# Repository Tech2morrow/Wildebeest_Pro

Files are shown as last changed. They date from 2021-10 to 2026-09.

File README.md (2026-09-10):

<p align="center">
  Wildebeest Pro — open autonomous robotics platform
</p>

<p align="center">
  
  
  
  
  
  
</p>

Wildebeest Pro is a complete reference implementation for a compact, four-wheel skid-steer autonomous robot. It combines an NVIDIA Jetson-class autonomy computer, an Arduino Uno safety-oriented base controller, LiDAR, camera, IMU, GNSS, ultrasonic ranging, reproducible simulation, and equivalent ROS 2 and ROS 1 interfaces.

> **Commissioning status:** the software, firmware, documentation, mock transports, and simulation models are implemented and host-tested. The physical robot has **not** been electrically or mechanically validated by this repository. Keep motor power disconnected until the BOM blockers, wiring checks, calibration, and staged acceptance tests are complete. This is not a safety-rated machine.

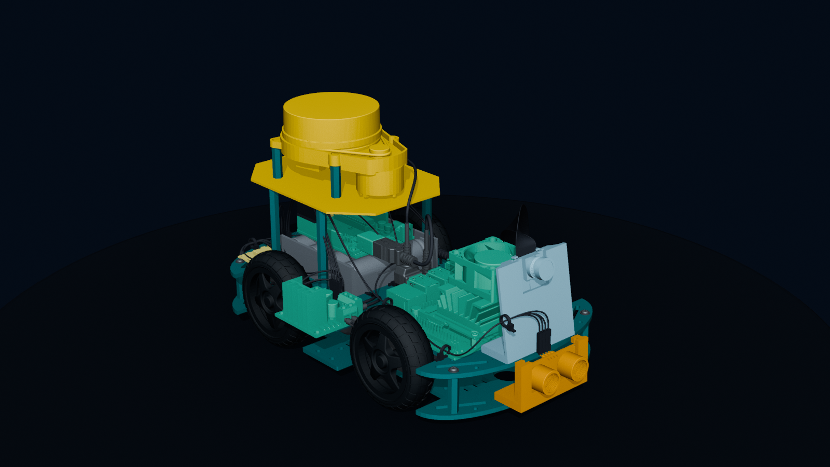
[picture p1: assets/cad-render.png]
Actual Wildebeest Pro CAD assembly rendered from the 595 placed STL components


## What is included

| Area | ROS 2 Jazzy | ROS 1 Noetic | Shared contract |
|---|---:|---:|---|
| Four-wheel description, TF, RViz | Yes | Yes | CAD-derived `33.622 mm` wheel radius, `121.843 mm` track, `117.150 mm` wheelbase |
| Serial base bridge and deterministic mock | Yes | Yes | CRC-16 frames, exact firmware identity gate, 300 ms MCU watchdog |
| Velocity arbitration and E-stop latch | Yes | Yes | navigation, teleop, joystick, and dashboard inputs require fresh commands |
| Encoder/IMU fusion and GNSS option | Yes | Yes | `/wheel/odometry`, `/odometry/filtered`, REP-103/105 frames |
| Navigation and mapping | Nav2 / SLAM Toolbox | move_base / gmapping | common sensor and frame semantics |
| Physics simulation | Gazebo Harmonic | Gazebo Classic legacy | four driven wheels and timeout-protected commands |
| Operator dashboard | Browser | Browser | rosbridge UI with offline-safe controls and responsive layout |

The ROS 2 path is recommended for new work. ROS 1 Noetic is maintained here as a migration and legacy profile; upstream Noetic is end-of-life.

## Run the software-only robot on any development PC

The most reproducible path is Docker Desktop (Windows/macOS) or Docker Engine with Compose (Linux). Git LFS is only needed when you want the full mechanical corpus.

```bash
git clone https://github.com/Tech2morrow/Wildebeest_Pro.git
cd Wildebeest_Pro
git lfs install
git lfs pull
```

Start the recommended ROS 2 mock robot:

```bash
docker compose --profile ros2 up --build ros2-mock
```

Or start the ROS 1 compatibility profile:

```bash
docker compose --profile ros1 up --build ros1-mock
```

These commands run the complete graph with a deterministic software base, so no serial device or motor hardware is required. Stop with `Ctrl+C`.

### Native ROS 2 on Ubuntu 24.04

```bash
./scripts/bootstrap.sh ros2
./scripts/build.sh ros2
source ros2_ws/install/setup.bash
ros2 launch wildebeest_bringup robot.launch.py use_sim:=true
```

For Gazebo physics:

```bash
ros2 launch wildebeest_gz simulation.launch.py use_rviz:=true
```

### Native ROS 1 on Ubuntu 20.04

```bash
./scripts/bootstrap.sh ros1
./scripts/build.sh ros1
source ros1_ws/devel/setup.bash
roslaunch wildebeest_bringup robot.launch use_sim:=true
```

For the legacy Gazebo demo:

```bash
roslaunch wildebeest_simulation demo.launch
```

The original Jetson Nano software image is not a native ROS 2 Jazzy target. The handbook explains supported split-compute, container, replacement-SBC, and ROS 1 legacy options before you choose an image.

## Architecture

```mermaid
flowchart LR
    L[2D LiDAR] --> J[Jetson autonomy]
    C[IMX219 camera] --> J
    G[GNSS] --> J
    J --> N[Localization, mapping, navigation]
    D[Dashboard / joystick] --> M[Velocity mux + E-stop gate]
    N --> M
    M --> B[ROS base bridge]
    B <-->|CRC-checked serial| A[Arduino Uno controller]
    A --> W[Four motors / wheels]
    E[Side encoders] --> A
    I[MPU6050 + ultrasonic] --> A
    A --> B
```

All command sources pass through arbitration. The base bridge will not move until it receives the exact firmware boot identity, an E-stop release cannot replay an old command, and both hardware and simulation paths stop on stale velocity input. See the [interface contract](docs/software/interfaces.md) and [serial protocol](docs/reference/serial-protocol.md).

### Sensor identification palette

The same high-contrast palette is applied to sensor visuals in ROS 1, ROS 2, RViz, Gazebo, and the CAD showcase. Colors identify hardware only; they never indicate live health or status.

| Sensor | Visual color | Hex |
|---|---|---|
| 2D LiDAR | Orange | `#E69F00` |
| MPU6050 IMU | Rose | `#CC79A7` |
| GNSS receiver | Yellow | `#F0E442` |
| IMX219 camera | Sky blue | `#56B4E9` |
| Front ultrasonic | Vermillion | `#D55E00` |

## Firmware, dashboard, and documentation

Build the Arduino Uno firmware with PlatformIO:

```bash
python -m pip install platformio
platformio run -d firmware/wildebeest_base
```

Run the local operator dashboard (Node.js 20+):

```bash
node dashboard/dev-server.mjs
```

Then open `http://127.0.0.1:8088/`. Live operation additionally requires a trusted rosbridge endpoint; the UI never bypasses the velocity multiplexer.

Build the handbook locally:

```bash
python -m pip install mkdocs-material
mkdocs serve -f docs/mkdocs.yml
```

Start with the [readiness guide](docs/getting-started.md), then follow [wiring](docs/hardware/wiring.md), [assembly](docs/hardware/assembly.md), [calibration](docs/calibration.md), and the [acceptance plan](docs/testing.md) in order. The spreadsheet [commissioning BOM](BOM/Wildebeest_Pro_BOM.xlsx) opens with a deliberate **BLOCKED** gate until safety-critical selections are verified.

## Mechanical design

The authoritative native model is [`Wildebeest_Pro_P&G.SLDASM`](<3D_Mechanical_Design/P&G Wildebeest_Pro/Wildebeest_Pro_P&G.SLDASM>). A matching `177 MB` AP203 [`Wildebeest_Pro_P&G.STEP`](<3D_Mechanical_Design/P&G Wildebeest_Pro/Wildebeest_Pro_P&G.STEP>) is available for CAD tools without SolidWorks. The requested `.asm` file does not exist; `.SLDASM` is the actual SolidWorks assembly.

The corpus also contains 595 placed component STL files. Read the [CAD guide](3D_Mechanical_Design/README.md) and [audited manifest](3D_Mechanical_Design/MANIFEST.md) before exporting ROS meshes: the raw files use millimetres, assembly coordinates, and more than 2.8 million triangles. The repository uses lightweight link-local primitives for portable runtime simulation and preserves the detailed sources through Git LFS.

Recreate the showcase image from the checked-in CAD exports with Blender 5.2+:

```bash
blender --background --python tools/render_cad.py -- --output assets/cad-render.png
```

## Repository map

| Path | Purpose |
|---|---|
| `ros2_ws/` | Primary Jazzy packages: base, bringup, description, Nav2, Gazebo |
| `ros1_ws/` | Noetic-compatible base, bringup, description, navigation, simulation |
| `firmware/wildebeest_base/` | Uno motor/encoder controller and fail-safe serial protocol |
| `config/robot.toml` | Version-neutral geometry, limits, serial, power, and topic defaults |
| `dashboard/` | Dependency-free mission-control web interface |
| `docs/` | MkDocs handbook, safety case, tests, operations, and troubleshooting |
| `BOM/` | Filterable commissioning workbook with cost formulas and release gate |
| `3D_Mechanical_Design/` | SolidWorks, STEP, STL, appearance, and CAD audit files |
| `tools/` | Protocol codec, mock MCU, preflight doctor, tests, and CAD renderer |

## Verify a checkout

On Windows:

```powershell
python -m pip install -r requirements-ci.txt
.\scripts\test.ps1
```

On Linux:

```bash
python3 -m pip install -r requirements-ci.txt
./scripts/test.sh
```

CI repeats protocol, dashboard, manifest, documentation, firmware, and container-build gates without downloading the 500+ MiB CAD corpus. Physical commissioning results must be recorded separately; a green software build is not evidence that an energized robot is safe.

## Contributing, credits, and licensing

Contributions are welcome through [the contributor guide](CONTRIBUTING.md). Security-sensitive reports follow [SECURITY.md](SECURITY.md).

Wildebeest Pro was created by Muhammed Nabeel. Thanks to Mr. Anouar Dhouibi for assistance with the original joystick teleoperation GUI concept, and to every open-source project on which this implementation builds.

Original project software and documentation are provided under the [MIT License](LICENSE). CAD and embedded vendor/reference assets may have separate or unconfirmed rights; inclusion does not relicense them. Review [THIRD_PARTY_NOTICES.md](THIRD_PARTY_NOTICES.md) before redistribution or commercial use.

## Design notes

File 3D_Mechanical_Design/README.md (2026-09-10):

# Wildebeest Pro mechanical design

This directory preserves the native SolidWorks design, a neutral STEP export,
and the component-level STL export set for the complete robot assembly.

Some component models, textures, and appearances have unconfirmed third-party
provenance. Read the repository [third-party notice](../THIRD_PARTY_NOTICES.md)
before redistributing or using the CAD corpus commercially.

## Start here

The authoritative top-level assembly is
[`Wildebeest_Pro_P&G.SLDASM`](<P&G Wildebeest_Pro/Wildebeest_Pro_P&G.SLDASM>).
The `.asm` filename mentioned in early project notes does not exist; `.SLDASM`
is the native SolidWorks assembly extension.

Users without SolidWorks can open the matching AP203 exchange model,
[`Wildebeest_Pro_P&G.STEP`](<P&G Wildebeest_Pro/Wildebeest_Pro_P&G.STEP>),
in a STEP-capable CAD program. There is **no single master assembly STL** in
this revision. The 595 `.STL` files are per-component exports whose filenames
begin with `Wildebeest_Pro_P&G -`.

Large CAD and mesh files are stored with Git LFS. After cloning, retrieve them
before opening the model:

```bash
git lfs install
git lfs pull
```

See [MANIFEST.md](MANIFEST.md) for checksums, measured mesh bounds, the sensor
evidence in the assembly, and the ROS export policy.

## Units and coordinate handling

The STEP file explicitly declares millimetres. STL does not carry unit
metadata, but the component coordinates match the millimetre-scale STEP model.
Unmodified STL files therefore require a `0.001` scale in URDF/Xacro.

Do not treat the current CAD origin or axes as a ROS frame. Before publishing a
production mesh:

1. Reorient it to REP-103 (`x` forward, `y` left, `z` up).
2. Put the base origin on the ground-plane projection of the chassis centre.
3. Export in metres, or explicitly apply `scale="0.001 0.001 0.001"`.
4. Use a decimated mesh for visuals and primitives or convex hulls for
   collision. Never use the 2.8-million-triangle component set as collision
   geometry.
5. Keep one normalized mesh per rigid ROS link. The assembly-exported STLs have
   transforms baked into their vertex coordinates and are not link-local.

The checked-in ROS descriptions intentionally use lightweight primitives until
a normalized, reviewed visual mesh is released. That keeps cloning, simulation,
collision checking, and CI practical.

## LiDAR and ranging-model status

The assembly contains `LiDAR Plate.SLDPRT` and its component STL. It also
contains a sensor model named `Radar_mb_1r2t_v1` in SolidWorks, STEP, and STL
formats. No RPLIDAR, YDLIDAR, LDS, or other explicitly named LiDAR sensor body
was found in the native/exchange corpus. Confirm the physical sensor model and
measure its optical origin before setting `laser_frame` or driver parameters.

## Engineering release checklist

Before manufacturing or hardware commissioning:

1. Resolve suppressed or missing references in the original SolidWorks version.
2. Assign real materials, mass, inertia, and centre-of-mass properties.
3. Check interference, fastener engagement, cable bend radius, ventilation,
   wheel clearance, and service access.
4. Create controlled drawings with tolerances and revision identifiers.
5. Measure the assembled wheel radius, left/right wheel-centre separation, and
   every sensor transform. CAD-derived values in the manifest are useful
   cross-checks, not substitutes for measurement.

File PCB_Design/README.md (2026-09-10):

# Electronics design status

The concept repository did not contain an editable schematic or PCB layout. The
current reference implementation therefore uses a documented, fused wiring
harness and off-the-shelf modules; it does **not** pretend that an unreviewed PCB
exists.

Before creating a carrier PCB, freeze the selected motor driver, regulator,
LiDAR interface, connectors and peak-current budget. A releasable design must
include source schematics, ERC/DRC reports, fabrication outputs, assembly BOM,
pick-and-place data, connector pinout, mounting drawing, revision marking,
power-on test plan and a license. See [`docs/hardware/wiring.md`](../docs/hardware/wiring.md)
for the current interconnect contract.

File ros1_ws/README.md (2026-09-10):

# Wildebeest Pro — ROS 1 Noetic compatibility workspace

This catkin workspace provides a complete ROS 1 path for the Wildebeest Pro four-wheel skid-steer robot: a CRC-protected Arduino bridge, side-encoder odometry, MPU6050 and HC-SR04 topics, NEO-6M/LiDAR/IMX219 launches, robot description, `robot_localization`, `move_base`, joystick/keyboard/remote command arbitration, diagnostics, and a Gazebo Classic autonomous demo.

> **Legacy support:** ROS Noetic reached end of life on 31 May 2025. It targets Ubuntu 20.04; the common Jetson Nano JetPack 4 image is Ubuntu 18.04 and cannot use official Noetic binaries directly. Use a maintained Ubuntu 20.04 environment/container or choose the repository's ROS 2 workspace for new deployments. Camera and GPIO access from containers needs host-specific integration.

The nominal wheel/chassis dimensions are CAD-derived: 0.033622 m radius, 0.025065 m wheel width, 0.121843 m left/right centre track, 0.117150 m axle wheelbase, and a 0.257 x 0.150 x approximately 0.031 m shell. They—and all limits, pin mappings, mass properties, covariance values, controller gains, and voltage thresholds—are **unverified commissioning defaults**. Skid-steer scrub means the effective track used by odometry usually differs from the CAD centre track. The software has mock/static tests but has not been validated on the author's physical hardware.

## Packages

| Package | Role |
| --- | --- |
| `wildebeest_base` | Safe serial transport, protocol validation, odometry, IMU/range/battery/diagnostic publication, software e-stop, and deterministic mock MCU |
| `wildebeest_description` | CAD-proportioned four-wheel URDF/Xacro, all sensor frames, four velocity transmissions, RViz model view, and Gazebo sensor hooks |
| `wildebeest_navigation` | Local encoder/IMU EKF, optional GNSS transform/global EKF, AMCL + `move_base`, GMapping, costmaps, and a smoke-test map |
| `wildebeest_bringup` | Hardware sensors, command mux, joystick, diagnostics, udev rules, and a composable robot launch |
| `wildebeest_simulation` | Gazebo Classic arena, `gazebo_ros_control`, four-wheel skid-steer control, sensors, RViz, and integrated navigation demo |

## Build

On an Ubuntu 20.04 machine with ROS Noetic installed:

```bash
cd ros1_ws
bash tools/install_noetic_dependencies.sh
source /opt/ros/noetic/setup.bash
catkin_make -DCMAKE_BUILD_TYPE=Release
source devel/setup.bash
```

Install the Arduino alias rule only after inspecting its VID/PID and adding a serial number if necessary:

```bash
bash tools/install_udev_rule.sh
```

The single source of truth for Arduino firmware is `../firmware/wildebeest_base`. It starts stopped, rejects malformed/out-of-range commands, reports hard/software stop state, and enforces a 300 ms command watchdog.

## Run without hardware

The fastest integration path uses Gazebo:

```bash
roslaunch wildebeest_simulation demo.launch
```

Send an initial pose if AMCL has not converged, then use RViz's **2D Nav Goal** tool. To smoke-test only the hardware graph and exact serial codec with an in-process MCU:

```bash
roslaunch wildebeest_bringup robot.launch use_sim:=true
```

`use_sim:=true` selects the mock base and disables physical sensor/joystick drivers by default; granular arguments may override those choices. BOOT always leaves the base stopped. Deliberately clear it, then send a fresh velocity command:

```bash
rosservice call /base/set_estop "data: false"
```

The mock follows the same wire protocol, watchdog, side-encoder kinematics, and soft-stop path as the serial transport. It is not a physics, exact sensor-timing, or hardware-safety qualification.

## Run on the robot

After wiring, firmware upload, calibration, and raised-wheel safety checks:

```bash
roslaunch wildebeest_bringup robot.launch
```

Useful profiles:

```bash
# Known indoor map: AMCL owns map -> odom
roslaunch wildebeest_bringup robot.launch navigation:=true map:=/absolute/path/site.yaml

# Create a map: GMapping owns map -> odom
roslaunch wildebeest_bringup robot.launch mapping:=true navigation:=false

# Outdoor GNSS fusion: global EKF owns map -> odom
roslaunch wildebeest_bringup robot.launch use_gps_localization:=true navigation:=false mapping:=false
```

`mapping:=true` takes precedence if both legacy mode booleans are supplied, so
GMapping and AMCL can never publish `map -> odom` together. With
`localization:=true` the local EKF owns `odom -> base_link`; with it disabled,
the base bridge becomes the single transform authority.

Never enable AMCL, GMapping, and the global GPS EKF together. The local EKF owns
`odom -> base_link` whenever localization is enabled; otherwise the base bridge
owns it. The MPU6050 has no absolute heading sensor, so the GNSS profile uses
odometry yaw and requires deliberate field validation.

## Stable interfaces

| Direction | Topic/service | Type / purpose |
| --- | --- | --- |
| Input | `/cmd_vel` | `geometry_msgs/Twist`, consumed only by the base bridge |
| Input | `/cmd_vel/remote` | Dashboard/remote `geometry_msgs/Twist` input to the mux; 0.35 s timeout, below local teleoperation |
| Input | `/wildebeest/estop` | `std_msgs/Bool`; locks the mux and latches/releases the MCU software stop |
| Input | `/base/set_estop` | `std_srvs/SetBool` service alternative |
| Input | `/base/reset_odometry` | `std_srvs/Empty`; reset the host-integrated raw odometry origin |
| Output | `/wheel/odometry` | Raw `nav_msgs/Odometry` from encoders |
| Output | `/odometry/filtered` | Local EKF estimate |
| Output | `/imu/data_raw` | Raw MPU6050 acceleration/rate; orientation is explicitly unavailable |
| Output | `/range/front` | `sensor_msgs/Range` from HC-SR04 |
| Output | `/battery_state` | `sensor_msgs/BatteryState` |
| Sensor | `/scan`, `/gps/fix`, `/camera/image_raw` | LiDAR, GNSS, and camera driver outputs |
| Health | `/diagnostics`, `/diagnostics_agg` | Link, heartbeat, watchdog, stop, protocol, battery, IMU, and range status |

Frames are `map -> odom -> base_link`, with `lidar_link`, `imu_link`, `gps_link`, `camera_link`/`camera_optical_frame`, `ultrasonic_front_link`, four wheel links, and a convenience `base_footprint` below `base_link`.

### Sensor visualization legend

The ROS 1 URDF and Gazebo Classic model use the same high-contrast palette so individual sensor housings remain easy to find against the blue/teal chassis:

| Color | Sensor | Link / frame |
| --- | --- | --- |
| Orange `#E69F00` | 2D LiDAR | `lidar_link` |
| Rose `#CC79A7` | MPU6050 IMU | `imu_link` |
| Yellow `#F0E442` | GNSS receiver | `gps_link` |
| Sky blue `#56B4E9` | IMX219 camera | `camera_link` (`camera_optical_frame` is axis-only) |
| Vermillion `#D55E00` | Front HC-SR04 ultrasonic sensor | `ultrasonic_front_link` |

These colors are visual identifiers only. They do not indicate readiness, diagnostics, range validity, or safety state; use topics, frame names, and `/diagnostics` as the authoritative runtime sources.

For a legacy consumer that requires `/odom`, set `odom_topic:=/odom` when including `wildebeest_base/launch/base.launch`. Do not expose both names as independently published odometry, and keep `publish_odom_tf:=false` whenever the EKF owns the transform.

Velocity producers publish to `/cmd_vel_nav`, `/cmd_vel/remote`, `/cmd_vel_keyboard`, or `/cmd_vel_joy`; `twist_mux` is the only normal owner of `/cmd_vel`. Priority is navigation < remote < keyboard < joystick, and remote/local teleoperation expires after 0.35 s. The joystick requires a held enable button. Any MCU hard/software-stop flag latches a host stop. After an explicit clear, the bridge waits for clean ODOM stop flags, discards cached velocity again, and requires a fresh command. A hard-wired, normally closed motor-power emergency stop remains required—software topics and the Arduino watchdog are additional layers, not substitutes.

## Tests

No ROS installation is needed for protocol, kinematics, mock-controller, XML, map, reference, and canonical-default checks:

```bash
python3 tools/run_checks.py
```

With Noetic sourced, also run:

```bash
catkin_make run_tests
catkin_test_results
roslaunch wildebeest_description display.launch
```

Before floor operation, calibrate effective wheel radius/track and encoder CPR, confirm all four wheel directions and both side encoder signs, characterize skid-steer scrub and stopping distance, measure serial-disconnect response, calibrate IMU/battery sensing/camera, validate LiDAR/GNSS frame orientation, and replace the demo map. The protocol intentionally treats the front/rear wheels on a side as one coupled drive and mirrors side telemetry into both wheel joints. See the root documentation for the complete evidence-driven commissioning process.

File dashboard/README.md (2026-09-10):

# Operator dashboard

This dependency-free web UI connects to ROS 1 or ROS 2 through
[`rosbridge_suite`](https://github.com/RobotWebTools/rosbridge_suite). It shows
odometry, LiDAR, IMU, GPS, range and battery freshness; renders a local scan;
and provides a dead-man joystick plus a latched software stop.

```bash
node dashboard/dev-server.mjs
# Open http://127.0.0.1:8088
```

On the robot, start rosbridge on port 9090 and expose only the network interface
you intend to trust. Browsers require `wss://` when this page is served over
HTTPS. The UI publishes standard `geometry_msgs/Twist` on
`/cmd_vel/remote`, which is routed through the robot's priority and timeout
multiplexer, and `std_msgs/Bool` on `/wildebeest/estop`. Do not remap the
dashboard directly to the base's `/cmd_vel` input because that would bypass
command arbitration.

Pose display prefers fresh `/odometry/filtered` data, then explicitly labels a
fallback to `/wheel/odometry` or simulator `/odom`. The fused-odometry health
row only reports the fused topic itself, so a raw source cannot mask an EKF
failure.

The on-screen stop is not a safety-rated control. The physical E-stop must cut
motor energy independently of the Jetson, Arduino firmware and network.

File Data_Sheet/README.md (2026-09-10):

# Datasheets and controlled references

Do not commit vendor PDFs without checking redistribution terms. Store local
copies outside the repository or add only files whose licenses permit it. Record
the exact manufacturer, part number, hardware revision, URL, document revision
and retrieval date in the BOM.

The minimum controlled set is:

- Jetson module/carrier and power-mode documentation
- Arduino Uno R3 electrical limits and pin map
- selected motor and quadrature encoder datasheets
- selected motor-driver, regulator, cells, BMS and fuse datasheets
- exact LiDAR protocol/timing documentation
- MPU-6050, GNSS, IMX219 and HC-SR04 module documentation

Module/carrier boards often differ from the underlying chip datasheet. Verify
the actual breakout board's regulator, pull-ups and logic levels as well.

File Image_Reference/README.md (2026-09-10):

# Images and media

Place publishable assembly photos, wiring close-ups, screenshots and test plots
here. Remove GPS coordinates and private surroundings before committing media.
Use descriptive names such as `rear-harness-rev-a.jpg` and include license/source
information when the image was not created for this project.

Repository brand artwork lives under [`assets/`](../assets/). The operator UI
lives under [`dashboard/`](../dashboard/).

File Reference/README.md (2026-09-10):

# Reference material

This directory is reserved for redistributable third-party reference material.
Prefer stable links in the documentation, pin versions where behavior matters,
and record license/source details. Project-owned interface specifications live
under [`docs/reference/`](../docs/reference/).

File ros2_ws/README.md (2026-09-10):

# Wildebeest Pro ROS 2 workspace

This workspace is the ROS 2 Jazzy implementation for the Wildebeest Pro
four-wheel skid-steer robot (controlled as a differential left/right pair).
It is intentionally self-contained and can be
used in three modes:

* **Mock:** exercises the complete base, odometry, TF, localization, and
  navigation interfaces without attached hardware.
* **Physical:** talks to the Arduino motor/sensor controller over a
  checksummed serial protocol and launches the Jetson-connected sensors.
* **Gazebo Sim:** spawns the robot in Gazebo Harmonic and bridges simulated
  sensors and drive topics to ROS 2.

## Packages

| Package | Purpose |
| --- | --- |
| `wildebeest_base` | Safe Arduino serial bridge, mock controller, odometry, IMU/range publishers, diagnostics |
| `wildebeest_description` | Parameterized four-wheel Xacro model, sensor frames, and Gazebo tags |
| `wildebeest_bringup` | Robot state, physical sensor drivers, command mux, EKF/GPS fusion, teleoperation |
| `wildebeest_navigation` | Nav2, SLAM Toolbox, example map, costmaps and RViz configuration |
| `wildebeest_gz` | Gazebo Harmonic world, spawning, and `ros_gz_bridge` configuration |

## Quick start (Ubuntu 24.04 / ROS 2 Jazzy)

```bash
sudo apt install python3-rosdep python3-colcon-common-extensions
sudo rosdep init  # only once per machine
rosdep update
cd ros2_ws
rosdep install --from-paths src --ignore-src -r -y --rosdistro jazzy
source /opt/ros/jazzy/setup.bash
colcon build --symlink-install
source install/setup.bash
```

Run without hardware:

```bash
ros2 launch wildebeest_bringup robot.launch.py use_sim:=true
ros2 topic pub --once /cmd_vel/teleop geometry_msgs/msg/Twist \
  "{linear: {x: 0.15}, angular: {z: 0.2}}"
```

Run the physical base (adapt the device path or create the recommended udev
rule described in `wildebeest_base/README.md`):

```bash
ros2 launch wildebeest_bringup robot.launch.py \
  transport:=serial serial_port:=/dev/wildebeest-base
```

Start mapping or navigation in another terminal:

```bash
ros2 launch wildebeest_navigation navigation.launch.py slam:=true
# or, with the included example/placeholder map:
ros2 launch wildebeest_navigation navigation.launch.py slam:=false
```

The included map only proves configuration wiring; create a real map before
autonomous operation.  Keep the robot on blocks for the first motor test and
verify emergency-stop behavior before allowing ground contact.

## Offline checks

The protocol and mock-controller tests do not need ROS installed:

```bash
python src/wildebeest_base/test/test_protocol.py
python src/wildebeest_base/test/test_mock_controller.py
python src/wildebeest_gz/test/test_safety_gate.py
python scripts/validate_workspace.py
```

On a Jazzy host, run the complete build and tests:

```bash
colcon build --symlink-install
colcon test --event-handlers console_direct+
colcon test-result --verbose
```

See each package README for parameters and hardware integration details.
Nothing in this workspace substitutes for current limiting, fusing, a
physical normally-closed emergency stop, or supervised hardware validation.

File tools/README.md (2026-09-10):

# Host-side tools

- `wildebeest_protocol.py` is the dependency-free reference codec.
- `mock_mcu.py` emulates the Arduino protocol for bridge testing.
- `robot_doctor.py` checks the repository and flags unverified commissioning data.

The reference codec enforces protocol v1's 128-byte complete-frame limit,
`0..20000 mV` battery field, and `0..2000 mm` front-range field.

Examples:

```bash
python3 -m unittest discover -s tools/tests -v
python3 tools/mock_mcu.py --demo --seconds 1
python3 tools/mock_mcu.py --tcp 8765
python3 tools/robot_doctor.py
```

The mock is a protocol and integration aid. It is not a dynamics, timing, or
safety certification model.

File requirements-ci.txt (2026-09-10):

# Pinned host-side release gates. ROS package dependencies remain managed by rosdep.
mkdocs-material==9.7.7
PyYAML==6.0.3

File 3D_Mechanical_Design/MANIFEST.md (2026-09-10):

# CAD and mesh manifest

Audit date: 2026-09-10

This is a curated manifest for the large mechanical corpus in
`P&G Wildebeest_Pro/`. It identifies authoritative files and integration risks
without duplicating hundreds of generated component paths.

## Authoritative artifacts

| Purpose | File | Bytes | SHA-256 |
| --- | --- | ---: | --- |
| Top-level native assembly | `Wildebeest_Pro_P&G.SLDASM` | 29,494,243 | `162D7D639AF203026D1699CD1CCE04777310D2187BA0D0FB7B2A0BE41C8F1110` |
| Full neutral assembly | `Wildebeest_Pro_P&G.STEP` | 177,374,833 | `423240EAEA069CD2CBF77FAEBC2609E1ACF4ED85AA4D9643296FB8CCB0925821` |
| Mobile-base subassembly | `Wildebeest_Nano.SLDASM` | 27,725,590 | `90F0D0D6D6009D073ED9B8FF8CA01DFBC3788B2C229E7CEF037FDC3F30640184` |
| LiDAR mounting plate | `LiDAR Plate.SLDPRT` | 52,600 | `244359235453B6E345CC5B0F83FF48933B2BB676D49AAFD1D3411C4AF1831840` |
| LiDAR plate mesh | `Wildebeest_Pro_P&G - LiDAR Plate-1.STL` | 1,484 | `20439837C4C6CBF34C9FCD64C5D5F5638B4BA27D4E14962C89A501D33BE7E319` |
| Radar-labelled sensor part | `Radar_mb_1r2t_v1.SLDPRT` | 406,771 | `D6C11294351D1CBC77754A92F3E1E73B76188B0AE3EABCEBA7CD79E90DC1C04C` |
| Radar-labelled neutral part | `Radar_mb_1r2t_v1.step` | 244,302 | `AA2ADC3C804F8225A5D29B2D92C611D475255397680E2959B6AC9AF039D2652E` |
| Radar-labelled placed mesh | `Wildebeest_Pro_P&G - Radar_mb_1r2t_v1-1.STL` | 811,684 | `70F614AFFF7E5FB44CBEB4F7AFCC7520ABD0AFA1F21CA2DE5679CBE83A33A4E3` |

The STEP header reports `SolidWorks 2025`, schema `CONFIG_CONTROL_DESIGN`
(AP203), and `SI_UNIT (.MILLI., .METRE.)` for length.

## Corpus summary

| Extension | Files | Bytes |
| --- | ---: | ---: |
| `.STL` | 595 | 141,496,180 |
| `.SLDPRT` | 59 | 54,908,882 |
| `.SLDASM` | 23 | 131,568,114 |
| `.STEP` | 3 | 177,644,837 |
| `.stp` | 1 | 1,731,524 |

The full directory contains 761 files and 539,451,840 bytes (514.46 MiB),
including SolidWorks appearances and scene assets. Every STL is binary; together
they contain 2,828,924 triangles. The STL files are all byte-distinct because
the assembly export baked component placement into vertex coordinates.

## Geometry observations

The union of all placed STL vertices is:

| Axis | Minimum (mm) | Maximum (mm) | Span (mm) |
| --- | ---: | ---: | ---: |
| X | 0.280 | 171.578 | 171.298 |
| Y | 88.255 | 243.898 | 155.642 |
| Z | 92.691 | 368.696 | 276.005 |

The four wheel meshes each measure approximately
`25.07 × 67.25 × 67.24 mm`. Their bounding-box centres imply a nominal wheel
radius near `0.03362 m`, left/right centre spacing near `0.12184 m`, and
front/rear centre spacing near `0.11715 m` under the apparent CAD-axis
interpretation. These are **audit clues only**: verify axis interpretation,
tire compression, and physical measurements before changing kinematic
parameters.

The LiDAR plate mesh spans about `100 × 1.5 × 132 mm`. The STEP product table
names the plate and `Radar_mb_1r2t_v1`, but it does not name an actual LiDAR
device. Consequently, this repository cannot yet assert a LiDAR make/model,
scan plane, connector clearance, field of view, or optical-frame transform from
CAD alone.

## Lightweight ROS mesh release policy

Do not copy the raw STEP file or all 595 STLs into both ROS workspaces. Produce
one versioned mesh set and share the same source artifacts between ROS 1 and
ROS 2 packaging:

1. Open the full STEP/native assembly and suppress cables, PCB micro-components,
   threads, fasteners, internal electronics, and appearance-only details.
2. Split only at moving or independently framed links: chassis, four wheels,
   and sensor/mast elements that need their own TF.
3. Normalize each link to its joint frame and REP-103 orientation.
4. Export a decimated `.dae` visual mesh in metres; target a complete-robot
   visual budget well below 100,000 triangles.
5. Model collision with boxes/cylinders or a small set of convex hulls. Never
   reuse detailed visual meshes for physics collision.
6. Store released meshes once in the description package and track them with
   Git LFS. ROS 1 and ROS 2 should consume equivalent generated artifacts,
   rather than keeping divergent manual copies.
7. Record source CAD revision, export settings, scale, axes, triangle count,
   and SHA-256 in this manifest for every released mesh.

Until that pipeline is reviewed, the parametric primitive descriptions are the
safe, portable default for RViz and simulation.

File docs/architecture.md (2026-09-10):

# System architecture

Wildebeest Pro uses a split-control architecture. Linux owns tasks that benefit from ROS and higher compute; the microcontroller owns bounded-latency I/O and the final software stop layer. The hard emergency stop remains electrical and independent of both.

## Functional layout

```mermaid
flowchart TB
    subgraph Safety[Independent safety path]
      BAT[Protected 2S battery] --> FUSE[Branch fuse]
      FUSE --> ESTOP[Latched motor E-stop]
      ESTOP --> MRAIL[Motor rail]
    end

    subgraph Jetson[Jetson Nano / ROS computer]
      PLAN[Navigation and velocity arbitration]
      STATE[Localization and TF]
      DIAG[Diagnostics and logging]
      CAM[IMX219 camera driver]
      LIDAR[2D LiDAR driver]
      GPS[NEO-6M GNSS driver]
      PLAN --> BRIDGE[Wildebeest base serial bridge]
      LIDAR --> STATE
      GPS --> STATE
      CAM --> PLAN
      STATE --> PLAN
    end

    subgraph MCU[Arduino Uno]
      SERIAL[Framed serial parser]
      WATCHDOG[300 ms command watchdog]
      CONTROL[50 Hz wheel control]
      IO[Encoders / MPU6050 / HC-SR04]
      SERIAL --> WATCHDOG --> CONTROL
      IO --> CONTROL
    end

    BRIDGE <-->|USB serial| SERIAL
    CONTROL --> DRIVER[L298N dual H-bridge]
    MRAIL --> DRIVER
    DRIVER --> MOTORS[Left and right geared motors]
    IO --> SERIAL
```

## Responsibility boundaries

| Layer | Owns | Must not own |
|---|---|---|
| Electrical safety | Fuse, battery protection, motor disconnect, correct rails, wiring protection | Dependence on a ROS message or Linux process |
| Arduino firmware | Motor pin state, encoder counts, command timeout, local E-stop input, bounded telemetry | Global planning, map state, or unbounded/blocking work in the control loop |
| Base bridge | Serial validation, unit conversion, device health, `/cmd_vel` to firmware commands, raw odometry publication | Autonomous decision-making or silently reusing stale telemetry |
| Velocity arbitration | Selects teleop/navigation/safety command source and enforces limits | Direct pin control |
| Localization | Fuses wheel odometry, IMU, and optionally GNSS; publishes a single authoritative transform | Sending motion commands |
| Navigation | Mapping/localization, costmaps, global/local planning, recoveries | Bypassing the velocity multiplexer or motor watchdog |
| Sensor drivers | Timestamped, framed sensor messages and diagnostics | Publishing transforms that contradict the robot description |

## Motion and stop chain

```mermaid
sequenceDiagram
    participant N as Navigation/teleop
    participant X as Twist multiplexer
    participant B as Base bridge
    participant A as Arduino
    participant H as L298N
    N->>X: velocity request
    X->>B: /cmd_vel (selected and limited)
    B->>A: validated serial command
    A->>H: PWM and direction
    Note over A,H: Only while E-stop is released and commands are fresh
    alt command stream stops
      A->>H: zero output after 300 ms watchdog
    else hard E-stop pressed
      H--xH: motor power removed electrically
      A->>B: E-stop state in telemetry
    end
```

There are deliberately multiple stop mechanisms:

1. The navigation or operator publishes zero velocity.
2. The velocity multiplexer times out stale command sources.
3. The base bridge stops transmitting on invalid state or shutdown.
4. The Arduino stops output after 300 ms without a valid command.
5. The hard E-stop removes motor energy even if every processor is stuck.

Each layer is tested independently. None is a substitute for the layer below it.

## ROS package map

The same package roles exist in `ros1_ws/src` and `ros2_ws/src`. Build-system and launch syntax differ, but the public contract in [ROS interfaces](software/interfaces.md) does not.

| Package | Role | Hardware dependency |
|---|---|---|
| `wildebeest_description` | Xacro/URDF, meshes, joints, sensor frames, RViz configuration | None |
| `wildebeest_base` | Arduino serial bridge, odometry/joint state publication, simulated/mock base | USB serial for real mode |
| `wildebeest_bringup` | Composed launch, sensor drivers, state estimation, velocity arbitration, parameters | Model-specific drivers in real mode |
| `wildebeest_navigation` | SLAM/localization and autonomous navigation configuration | `/scan`, TF, odometry; GNSS only for outdoor extensions |
| `wildebeest_gz` (ROS 2) | Gazebo Sim world, spawn and simulated sensors/control hooks | None |
| `wildebeest_simulation` (ROS 1) | Gazebo Classic world, control/sensor hooks and navigation demo | None |

The description is not generated from the SolidWorks assembly. Its inertias, collision geometry, origins, and joint axes must be independently reviewed against the constructed robot.

## Coordinate-frame contract

Frame names follow REP-105 conventions:

```mermaid
graph TD
    MAP[map] --> ODOM[odom]
    ODOM --> BASE[base_link]
    BASE --> FOOT[base_footprint]
    BASE --> LEFT[left_wheel_link]
    BASE --> RIGHT[right_wheel_link]
    BASE --> IMU[imu_link]
    BASE --> GPS[gps_link]
    BASE --> LIDAR[lidar_link]
    BASE --> CAMERA[camera_link]
    CAMERA --> OPT[camera_optical_frame]
    BASE --> SONAR[ultrasonic_front_link]
```

- `map -> odom` is owned by localization/SLAM when enabled.
- `odom -> base_link` is owned by exactly one odometry/localization component.
- `base_link -> base_footprint` is a fixed convenience transform to the ground-projected frame; sensor extrinsics are also supplied by `robot_state_publisher` from the URDF.
- Camera optical axes follow the ROS optical-frame convention; do not reuse `camera_link` as the optical frame.
- Wheel joints are published through `/joint_states`; no second node may publish the same joints.

Run a TF audit whenever launch composition changes. Duplicate transform publishers can look plausible in RViz while corrupting navigation.

## Localization modes

| Mode | World transform | Inputs | Intended environment |
|---|---|---|---|
| Wheel-only bench | none or fixed | Encoders | Lifted-wheel and short motion tests |
| Indoor local odometry | `odom -> base_link` | Encoders + IMU rate/acceleration | Teleoperation and local control |
| Indoor mapped navigation | `map -> odom` plus local odometry | LiDAR + encoders + IMU | Structured indoor spaces |
| Outdoor georeferenced extension | map/geodetic alignment plus local odometry | Encoders + IMU + GNSS; LiDAR as applicable | Open sky after GNSS validation |

The MPU6050 has no magnetometer, and a NEO-6M position fix does not provide reliable stationary heading. Absolute yaw therefore requires motion-derived GNSS course, scan matching, an added heading sensor, or another validated source. Do not configure an estimator as though the IMU supplies absolute magnetic heading.

## Timing and units

- ROS-facing values use SI units: metres, radians, seconds, metres per second, and radians per second.
- The firmware control loop target is 50 Hz.
- Default telemetry targets are odometry 20 Hz, optional IMU 50 Hz, and range 10 Hz.
- Host and MCU sequence/timestamp behavior is defined in the [serial protocol](reference/serial-protocol.md).
- Sensor timestamps should represent acquisition time where the driver exposes it, not merely callback time.
- The Jetson and any remote workstation need synchronized clocks for distributed ROS; record the time-sync method and measured offset.

Rates are budgets, not guarantees. Acceptance testing records observed rate, jitter, dropouts, CPU load, and temperature on the final image.

## Degraded behavior

| Failure | Required behavior |
|---|---|
| ROS process crash or USB disconnect | Arduino watchdog commands zero motor output |
| Invalid/corrupt serial frame | Discard frame, increment diagnostics; never reinterpret it as motion |
| Encoder loss | Stop autonomous motion; do not continue open-loop unless explicitly in a restrained test mode |
| IMU loss | Report degraded localization; use only a separately validated fallback |
| LiDAR loss/stale scan | Navigation stops; teleoperation, if allowed, remains low-speed and directly supervised |
| GNSS loss | Outdoor global objective pauses; local obstacle stop behavior remains available |
| Camera loss | Vision-dependent behaviors stop; base safety path remains unaffected |
| Low battery or regulator brownout | Command stop, log event, and shut down cleanly; hardware protection is the final backstop |
| Jetson thermal throttling | Abort autonomy if control deadlines or perception freshness cannot be maintained |

These responses are design requirements. Mark each as verified only after the corresponding fault-injection test passes.

## Compute-platform limitation

The Jetson Nano and its JetPack 4 software stack are legacy constraints. The maintained ROS 2 workspace targets Jazzy/Ubuntu 24.04, which is suitable for a supported workstation or capable 24.04 arm64 SBC but not a stock Nano image. Three honest choices exist: keep the Nano as a vendor-driver sensor computer in a validated split deployment, undertake an experimental community/container/source port and own all evidence, or revise the compute hardware. A replacement SBC is a hardware revision: power, CSI camera, device paths, cooling, performance, mounts, EMC and safety tests all repeat.

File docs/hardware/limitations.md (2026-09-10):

# Hardware limitations and upgrade path

Wildebeest Pro intentionally preserves the components named in the original concept, but several are legacy, underspecified, or unsuitable for unattended/production robotics. This page defines honest support boundaries and the evidence required to change them.

## Limitation matrix

| Component/design choice | What it enables | Principal limitation | Upgrade trigger |
|---|---|---|---|
| Jetson Nano + JetPack 4 | CSI camera and CUDA-era edge compute on the original platform | Legacy vendor OS; does not natively match ROS 2 Jazzy/Ubuntu 24.04; limited compute/memory by modern autonomy standards | Need maintained native Jazzy, higher perception rate, more memory, or current security support |
| Arduino Uno | Simple deterministic 5 V I/O and widely understood tooling | Limited CPU/RAM/timers/interrupt pins; no hardware safety certification; USB serial lacks industrial robustness | Missed encoder edges, timing jitter, more sonar/I/O, current control, CAN/RS-485, or stronger diagnostics needed |
| L298N | Familiar dual brushed-motor bridge | Bipolar voltage drop, heat/inefficiency, limited diagnostics/protection compared with modern MOSFET bridges | Measured stall/continuous current, rail drop, temperature, braking or fault-reporting needs exceed validated envelope |
| Original encoder/KY-040 concept | Basic quadrature odometry | Module name may describe a hand encoder rather than a motor-rated encoder; resolution/output type/max speed unknown | Edge rate, durability, resolution or mounting fails H2/H4 tests |
| MPU6050 | Low-cost acceleration and angular rate | No magnetometer/absolute yaw; bias, drift, vibration and I²C integrity constraints | Need reliable heading, lower drift/noise, temperature calibration, timestamping or higher integrity |
| NEO-6M GNSS | Basic outdoor position/NMEA | No reliable stationary heading; multipath/obstruction; not precision or safety rated | Mission needs robust lane-level/centimetric positioning, heading at rest, integrity monitoring or high update rate |
| Unspecified 2D LiDAR | Planar ranging for mapping/obstacles | Exact driver/performance unknown; one plane misses over/under-plane objects and difficult surfaces | Identification/support unavailable or environment requires 3D/overhang/low-obstacle coverage |
| IMX219 camera | Compact CSI vision | Depends on light/lens/focus/vendor CSI stack; rolling shutter and transport latency may constrain motion | Vision task cannot meet measured accuracy/latency/environment envelope |
| HC-SR04 | Low-cost near-field ranging | Acoustic cone, soft/angled target failures, crosstalk, temperature effects; no-return is ambiguous | Safety/coverage needs reliable near-field detection or environmental sealing |
| 2S Li-ion + adjustable buck module | Compact mobile energy | Exact cells/BMS/charger/regulator are unknown; marketplace specifications and CAD labels are not evidence | Any lack of traceability/protection/margin, or compute/motor transient/thermal failure |
| CAD-derived chassis | Rich original mechanical concept | No released drawings/material/tolerances/load case; source assembly includes vendor/reference parts | Fit, structural, center-of-gravity, service, weather or manufacturability review fails |

## Compute choices

### Preserve the Nano

Keep its validated JetPack image for CSI/GPU/vendor drivers and run the Jazzy graph on an Ubuntu 24.04 workstation. This is a split-compute experiment until sensor transport, time synchronization, network security, bandwidth, disconnect behavior and stop behavior pass acceptance. The Arduino watchdog remains local and independent of the network.

### Experimental container or source build

A community container/source path on the Nano may be useful for research, but it is not the repository's supported baseline. Record base image digest, kernel/L4T, architecture, ROS source revisions, patches, device mounts/privileges, GPU/CSI behavior, time synchronization, performance and update strategy. Never use a privileged container as an unexplained device-access shortcut.

### Replace the compute module

A capable SBC with supported Ubuntu 24.04 arm64 can provide a native Jazzy path. Select it from measured workload and interfaces—not benchmark marketing. Replacing the Nano requires a new hardware revision and repeat of power, transient, thermal, mounting, mass, camera, USB/UART/I²C/GPIO levels, networking, drivers, calibration and acceptance tests.

## Drive electronics

Before retaining the L298N, measure both motors' stall current at the intended motor rail using a safe method, sustained mission current, startup/reversal transients, loaded motor voltage, braking behavior and driver temperature in the closed enclosure. Compare these with the exact module's documented DC/peak/thermal envelope and wiring/connector limits.

A replacement bridge should be selected for:

- verified supply and per-channel continuous/peak current with thermal margin;
- logic compatibility/isolation and boot-safe input behavior;
- current limiting/sensing and hardware fault output where needed;
- braking/coast behavior appropriate to stopping requirements;
- reverse-polarity/transient/overtemperature protections;
- available driver/firmware interface and diagnostic coverage.

Changing the bridge can change direction truth tables, PWM frequency/polarity, deadband, electrical braking, current draw and stop behavior. Treat it as safety-relevant.

## Sensing coverage gaps

No single installed sensor proves free space:

- A 2D scan plane can pass beneath a tabletop or above a low object.
- Ultrasonic sensors can miss angled, soft or narrow targets and interfere with each other.
- Monocular camera depth depends on algorithms, calibration, texture and light.
- Wheel odometry fails under slip/lift.
- IMU yaw drifts without an absolute reference.
- GNSS fails indoors and can be wrong near reflective/obstructing structures.

Define the hazard geometry and environment first, then select complementary sensing and physical barriers. A safety-rated scanner/bumper/controller cannot be replaced by combining several hobby sensors in software.

## Real-time and bandwidth limits

The Uno control loop is 50 Hz and serial telemetry shares a 115200 baud link. Measure utilization and worst-case loop/encoder behavior with ODOM 20 Hz, IMU 50 Hz and RANGE 10 Hz enabled. Increasing rates or adding verbose text can starve control or overflow buffers. High-bandwidth camera, LiDAR and GNSS streams therefore remain off the MCU link.

The Jetson/workstation path must meet end-to-end age requirements, not just average rate. Record CPU/GPU/memory, thermal throttling, USB contention, storage write load, DDS/network bandwidth, drops and worst observed timestamp age under the actual mission workload.

## Environmental limits

Unless a released revision proves otherwise, assume:

- indoor, dry, clean, noncondensing use only;
- level, firm surfaces with physical edge barriers;
- no ingress, impact, chemical, UV or electromagnetic compatibility rating;
- no operation near combustible atmospheres, road traffic or the public;
- no lifting/carrying payload that can harm a person;
- no unattended charging or operation.

Set numeric temperature, humidity, slope, payload, lighting and surface limits from actual component specifications and tests.

## Upgrade decision record

For any upgrade, record:

1. requirement the baseline cannot meet;
2. measured evidence of the limitation;
3. candidate part and exact datasheet/revision;
4. electrical/mechanical/software/interface impact;
5. new failure modes and safety controls;
6. files/configuration/calibration changed;
7. acceptance stages repeated and evidence;
8. fallback/recovery plan.

Do not advertise an upgrade as “drop-in” unless every affected interface and test demonstrates that claim.

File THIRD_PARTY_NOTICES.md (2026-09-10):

# Third-party and CAD asset notice

The root MIT license covers original Wildebeest Pro software and documentation contributed under that license. It does **not** automatically relicense third-party material embedded in the mechanical-design corpus.

## CAD/reference assets

`3D_Mechanical_Design/P&G Wildebeest_Pro/` contains a complete project assembly plus reference models, appearances, textures, and scene files whose filenames identify or resemble commercial components. Examples include NVIDIA Jetson Nano, Arduino Uno, Noctua NF-A4x20, IMX219, u-blox/GNSS, MPU6050, L298N/LM2596 modules, connectors, battery cells, and SolidWorks appearance assets. `assets/cad-render.png` is a rendered derivative of that assembly and carries the same provenance caveat.

No reliable per-asset license or provenance metadata was found alongside many of these files during the 2026-09-10 repository audit. Their inclusion preserves the existing design and is not a statement that every asset is owned by the project, redistributable under MIT, approved by a vendor, or suitable for commercial manufacture.

Before redistributing, selling, or using the CAD corpus commercially, users must:

1. identify the source and applicable terms for each reference model, texture, and appearance;
2. replace or remove any asset for which they cannot establish appropriate rights;
3. respect applicable trademark, design, export, and product-documentation requirements; and
4. obtain independent legal advice where the intended use requires it.

Product names and marks remain the property of their respective owners. References describe compatibility or design intent and do not imply endorsement.

## Runtime dependencies

ROS, Gazebo, Nav2, robot_localization, rosbridge, PlatformIO, Arduino libraries, MkDocs Material, Blender, Docker images, and other dependencies are obtained separately and remain under their own licenses. Review the packages installed for the selected runtime and distribute their notices as required.

If you can document the original source and license of an asset, please open a contribution with that evidence so this notice and the CAD manifest can be made more precise.

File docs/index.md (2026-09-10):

# Wildebeest Pro

Wildebeest Pro is an open, four-wheel skid-steer robotics platform built around a Jetson Nano and an Arduino Uno. Two wheels on each side share one differential-drive command, while the Jetson runs perception, localization, planning, and the ROS graph. The Arduino owns time-critical encoder sampling, motor output, range acquisition, and the motion watchdog. The design accommodates a 2D LiDAR, IMX219 CSI camera, MPU6050 IMU, NEO-6M GNSS receiver, wheel encoders, and HC-SR04 ultrasonic ranging.

This handbook turns the original mechanical concept into a reproducible integration target for both ROS 1 and ROS 2. It is written for builders who intend to measure their own hardware, preserve safety controls outside Linux, and prove each subsystem before attempting autonomous motion.

!!! danger "Prototype, not a safety-rated machine"
    The repository is not evidence of electrical certification, functional-safety certification, or safe operation around people. CAD filenames show design intent only. A competent builder must validate the exact modules, wiring, protection devices, structural parts, software revision, and operating environment. Keep the robot lifted or mechanically restrained until the staged acceptance plan authorizes floor testing.

## What is implemented

The intended repository layout is one hardware contract with two ROS integrations:

| Area | Purpose | Evidence level |
|---|---|---|
| `firmware/wildebeest_base` | Arduino motor, encoder, watchdog, optional IMU/range bridge | Bench verification required on the final harness |
| `ros2_ws/src` | ROS 2 base, description, bringup, navigation, and simulation packages | Build/static tests plus simulation where available |
| `ros1_ws/src` | ROS 1 equivalents using the same topics, frames, and serial protocol | Build/static tests plus simulation where available |
| `3D_Mechanical_Design` | Original SolidWorks/STEP design assets | Mechanical concept; dimensions and fit must be checked |
| `docs` | This integration, safety, calibration, and operations handbook | Normative project guidance |

Passing a software build does **not** mean a physical robot is safe or calibrated.

## Choose a path

```mermaid
flowchart LR
    A[Inventory exact hardware] --> B[Complete configuration record]
    B --> C[Assemble without battery]
    C --> D[Continuity and rail checks]
    D --> E[Flash Arduino]
    E --> F{Runtime}
    F -->|Recommended| G[ROS 2]
    F -->|Legacy support| H[ROS 1 Noetic]
    G --> I[Simulation]
    H --> I
    I --> J[Lifted-wheel bench test]
    J --> K[Low-speed supervised test]
    K --> L[Localization and autonomy]
```

New builders should follow this order:

1. Read [readiness and compatibility](getting-started.md) and the [safety case](safety.md).
2. Reconcile the [bill of materials](hardware/bom.md) and [hardware limitations](hardware/limitations.md) against the actual parts in hand.
3. Record every TBD in the [configuration record](reference/configuration-record.md).
4. Build using the [wiring](hardware/wiring.md) and [assembly](hardware/assembly.md) gates.
5. Calibrate every measurement in [calibration](calibration.md).
6. Build [ROS 2](software/ros2.md) or [ROS 1](software/ros1.md), then prove behavior in [simulation](software/simulation.md).
7. Execute the [test and acceptance plan](testing.md) before autonomous operation.

## Design principles

- **Power safety is physical.** The emergency stop must remove motor energy independently of ROS, USB, and the Jetson.
- **A stopped command is the default.** The Arduino starts disabled and stops the motors when its 300 ms command watchdog expires.
- **One contract, two ROS versions.** Topic semantics, frame names, SI units, and the serial protocol remain equivalent across ROS 1 and ROS 2.
- **Measured configuration beats nominal configuration.** Wheel radius, track width, counts per revolution, voltage thresholds, sensor transforms, and direction signs come from the finished robot.
- **Simulation precedes floor motion.** Launch, TF, velocity arbitration, localization, and navigation are exercised without energized motors first.
- **Diagnostics are part of control.** Stale data, reset counters, invalid packets, estimator disagreement, undervoltage, and lost transforms are operating conditions—not cosmetic warnings.

## Support status

ROS 2 is the primary path for new development. ROS 1 Noetic support exists for migration and legacy deployments, but Noetic reached end of life on 31 May 2025 and no longer receives official fixes or security updates. See [readiness and compatibility](getting-started.md) before choosing an operating-system image.

## How to read command examples

Commands assume the repository root is the current directory. Shell placeholders use angle brackets, for example `<serial-device>`; replace them and remove the brackets. Never paste a command that changes device permissions or motor state until you understand its scope.

The shortest software-only smoke test is:

=== "ROS 2"

    ```bash
    ./scripts/bootstrap.sh ros2
    ./scripts/build.sh ros2
    source ros2_ws/install/setup.bash
    ros2 launch wildebeest_bringup robot.launch.py use_sim:=true
    ```

=== "ROS 1"

    ```bash
    ./scripts/bootstrap.sh ros1
    ./scripts/build.sh ros1
    source ros1_ws/devel/setup.bash
    roslaunch wildebeest_bringup robot.launch use_sim:=true
    ```

If a referenced package or launch argument is absent in the checked-out revision, treat that as an implementation gap and open an issue with the commit ID and command output; do not improvise a hardware workaround.

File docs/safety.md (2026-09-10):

# Safety case

This safety case states the minimum claims and evidence expected for a research prototype. It does not certify Wildebeest Pro under any machinery, battery, radio, automotive, medical, or functional-safety standard. The person or organization building and operating the robot remains responsible for applicable law, standards, workplace rules, and risk assessment.

## Safety objective

The prototype should remain de-energized or stopped by default, limit the energy and area of supervised tests, detect common stale/faulted states, and provide a hardware means to remove motor energy independent of software.

## Safety claims and current evidence

| ID | Claim | Design mechanism | Repository evidence | Physical evidence required |
|---|---|---|---|---|
| S-01 | Motor energy can be removed independently of software | Rated NC main E-stop contact in motor branch | Wiring requirement only | Continuity and loaded interruption test on as-built harness |
| S-02 | Broken E-stop sense wiring is detected | Separate NC auxiliary contact: A1 `LOW` healthy, open/`HIGH` asserted | Firmware input/pull-up and status flag | Press, unplug and single-wire-break tests |
| S-03 | MCU starts stopped | Watchdog flag initialized; outputs disabled until valid command | Firmware source/tests | Scope/driver-output test across power/reset states |
| S-04 | Lost host commands stop motion | Independent 300 ms MCU command watchdog | Firmware source/protocol tests | USB pull/process kill under load; measured stop timing |
| S-05 | Software stop overrides commands | Latched software-stop state | Firmware/bridge behavior | Service, reconnect and race-condition tests |
| S-06 | Commands are bounded | Firmware rejects commands beyond configured ceilings | Parser/tests | Confirm final limits safe for mass/surface/environment |
| S-07 | Corrupt commands do not actuate | Length/schema/range/CRC validation | Cross-language codec tests | Serial fault injection with outputs observed |
| S-08 | Only one source controls the base | Velocity multiplexer and topic ownership contract | Launch/graph tests | Pre-run graph audit |
| S-09 | Low battery cannot silently corrupt control | Monitoring plus pack protection and stop policy | Monitoring code; stop disabled until calibrated | Divider safety, threshold, BMS and brownout tests |
| S-10 | Stale critical sensing blocks autonomy | Driver diagnostics and navigation configuration requirement | Configuration/tests where implemented | Sensor disconnect tests at operating speed |

“Repository evidence” means design intent or software behavior under test. It does not close the physical claim.

## Hazard register

| Hazard | Causes | Required controls | Residual decision owner |
|---|---|---|---|
| Unexpected/runaway motion | Bad command, reversed feedback, process/USB failure, boot transient, driver fault | Hard motor disconnect, MCU watchdog, boot-safe outputs, command bounds, stand testing, exclusion zone, observer | Test lead |
| Crush/pinch/collision | Wheels, gears, chassis momentum, autonomous planner | Guards, low staged limits, controlled area, reachable E-stop, no people in path | Operator/site owner |
| Fall from edge/stairs | Map/sensor/localization failure | Physical barriers; never rely only on perception/geofence | Site owner |
| Battery fire/venting | Damaged/counterfeit cells, short, wrong charger, overcurrent/temperature | Traceable protected pack, correct charger, fuse, enclosure, inspection, site incident plan | Electrical safety owner |
| Electrical damage/fire | Polarity error, undersized wire, regulator fault, backfeed, loose terminal | Reviewed schematic, branch protection, current-limited first power, rated wiring/connectors, guards, thermal tests | Electrical safety owner |
| Compute brownout/reset | Motor transient, inadequate regulator, wiring drop | Separate/engineered rails, power budget, scope transients, reset-aware host, stopped MCU default | Integration owner |
| Thermal injury/failure | L298N/regulator/Jetson overload, blocked fan | Thermal margin, airflow, limits, shutdown criteria, guarded hot surfaces | Integration owner |
| Sensor-induced unsafe navigation | Blind spot, glare, crosstalk, multipath, stale timestamps | Multi-layer sensing, freshness/quality gates, conservative speed, scenario tests, operator | Autonomy owner |
| Cyber/unintended network command | Open ROS graph, wrong domain/master, compromised host | Isolated trusted network, firewall/security configuration, graph audit, physical stop | System owner |
| Data/privacy exposure | Camera images, GNSS tracks, network/bag logs | Consent, minimization, access/retention controls, redaction | Data owner |
| Mechanical ejection/failure | Loose wheel/battery/fastener, cracked printed part | Retention, inspection marks, material/process evidence, impact checks | Mechanical owner |

Add site-specific hazards. A risk matrix is meaningful only when severity/likelihood definitions and acceptance authority are declared by the operating organization.

## Non-negotiable controls

### Hard emergency stop

- The motor-energy interruption works with Jetson, Arduino and software absent or frozen.
- The main contact is normally closed in the healthy/released state and opens when pressed.
- A mechanically linked, isolated NC auxiliary contact closes A1 to Arduino ground while healthy. Pressed, disconnected, or broken-wire state opens it; `INPUT_PULLUP` reads `HIGH` and firmware inhibits motion.
- The E-stop is latching, visible, labeled, reachable by the observer, and reset does not itself create motion.
- Contact/interrupt ratings and DC behavior are established from the selected device and expected fault current.

If the available button cannot provide the required independent contacts and ratings, use a properly designed contactor/relay/safety device. Do not improvise motor current through a panel switch or GPIO.

### Protection and isolation

- A fuse/overcurrent device is close to the energy source and protects the downstream conductor/connector envelope.
- A service disconnect enables safe maintenance.
- Battery/BMS protection is present but is not used as the normal on/off control.
- Motor return current does not flow through logic boards or signal conductors.
- Regulators are set with loads disconnected and validated for transients/thermal conditions.
- Exposed terminals and rotating/pinch parts are guarded.

### Software defaults

- No motion at MCU boot, reset, serial connect, ROS launch, estimator reset or E-stop reset.
- Commands expire; no “last command forever.”
- Invalid packets are rejected and diagnosed.
- Simulation and hardware drivers cannot both control one base.
- Navigation stops on stale mandatory transform/sensor/odometry data.
- Recovery after a stop is deliberate and requires a fresh command.

## Battery rules

- Use a traceable, professionally assembled protected pack and approved charger.
- Follow manufacturer limits for storage, charge, discharge, temperature, inspection and disposal.
- Never charge unattended or while the robot is operating.
- Do not charge a damaged, swollen, wet, hot, deeply discharged or suspect pack.
- Prevent reverse connection, abrasion, crushing, puncture and conductor shorting.
- Define a site-specific isolation/fire response before bringing the pack into the test area.
- Do not publish generic extinguishing advice as a substitute for the exact pack and facility procedure.

The battery voltage, warning threshold, stop threshold, fuse and wire size remain safety-critical TBDs until supported by the actual pack/load design. Default firmware voltage values and divider components are commissioning aids, not validated pack protection.

## Operating limits

The following must be measured and approved in the configuration record before floor operation:

- maximum linear/angular velocity and acceleration;
- stopping distance on each authorized surface and battery/load condition;
- maximum slope, step/edge exposure and payload;
- minimum sensor freshness/quality and obstacle size/distance;
- compute/motor-driver/regulator temperature and current limits;
- minimum safe radio/network quality where remote commands are used;
- indoor/outdoor, light, dust, moisture and ambient-temperature envelope.

Until then, the robot remains a restrained bench prototype.

## Safety validation

Perform failures rather than assuming them:

- press E-stop and break/unplug the auxiliary sense loop;
- remove USB and kill the base bridge at low speed;
- send truncated, bad-CRC, duplicate, delayed and out-of-range serial frames;
- reset Arduino and Jetson independently;
- disconnect each encoder and critical sensor;
- pause/stall clocks and inject stale timestamps in simulation/replay;
- block the fan and approach thermal thresholds only under a controlled non-damaging test plan;
- introduce motor load/transients with current limiting and scope the compute rail;
- attempt launch with duplicate TF/command publishers and require detection.

For every test, record initial state, stimulus, expected safe state, measured response time, final state, logs, video/instrument trace, versions and result.

## Stop-work conditions

Stop, isolate and label the robot out of service after:

- unexpected motion or failure of any stop layer;
- damaged/swollen/hot battery or unexplained power odor/noise;
- blown fuse without known benign test cause;
- recurring brownout, watchdog, CRC, encoder or sensor freshness faults;
- loose wheel, motor, battery, sensor, board or structural crack;
- temperature/current outside the approved envelope;
- missing configuration provenance or unreviewed safety-critical change.

Do not “temporarily” bypass a fuse, E-stop, watchdog, diagnostic, limit, or sensor gate to finish a demo.

## Known platform limitations

- Jetson Nano/JetPack 4 is a legacy compute platform and does not natively match the repository's supported ROS 2 Jazzy/Ubuntu 24.04 profile.
- ROS 1 Noetic is end-of-life.
- L298N efficiency, voltage drop, heat and lack of modern diagnostics may be unsuitable for the selected motors.
- MPU6050 lacks an absolute-heading magnetometer.
- NEO-6M-class GNSS is not a safety-rated localization/geofence source and is vulnerable to obstruction/multipath.
- HC-SR04 coverage is narrow/material-dependent and timeout does not mean clear space.
- A single 2D LiDAR plane misses obstacles above/below the plane and transparent/specular/absorptive objects can be difficult.
- IMX219 vision depends on light, focus, exposure and compute latency.
- The baseline has no safety-rated bumper, safety scanner, redundant drive cutoff or certified controller.

These limitations constrain use; they are not merely future feature ideas.

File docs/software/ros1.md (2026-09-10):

# ROS 1 Noetic

ROS 1 support targets **Noetic on Ubuntu 20.04** for legacy and migration use. ROS 1 Noetic reached end of life on 31 May 2025: there are no new official security updates, fixes, or binary releases. Use an isolated, documented environment and prefer ROS 2 Jazzy for new work.

!!! danger "Legacy deployment risk"
    Do not expose an end-of-life ROS 1 master or host to an untrusted network. ROS 1 graph connectivity does not provide modern authentication or authorization. Keep the robot behind a controlled network boundary and maintain a migration plan.

## Package parity

The ROS 1 workspace mirrors the public roles and interface semantics of ROS 2:

| Package | Purpose |
|---|---|
| `wildebeest_description` | URDF/Xacro, meshes, sensor frames and RViz configuration |
| `wildebeest_base` | Arduino serial bridge/mock, odometry/joints/raw IMU/range and diagnostics |
| `wildebeest_bringup` | Description, base, model-specific sensors, state estimation and command arbitration |
| `wildebeest_navigation` | ROS navigation/SLAM configuration and maps |

The shared firmware and [serial protocol](../reference/serial-protocol.md) are the source of truth; a second copy of firmware under a ROS package must not drift from them.

## Install and build

Install Noetic using the archived official ROS instructions appropriate to Ubuntu 20.04, then from the repository root:

```bash
source /opt/ros/noetic/setup.bash
./scripts/bootstrap.sh ros1
./scripts/build.sh ros1
source ros1_ws/devel/setup.bash
```

Manual equivalent:

```bash
source /opt/ros/noetic/setup.bash
rosdep install --from-paths ros1_ws/src --ignore-src -r -y \
  --rosdistro noetic --skip-keys gscam
cd ros1_ws
catkin_make
source devel/setup.bash
catkin_make run_tests
catkin_test_results
```

Use a normal user account and do not mix Python packages from an unrelated virtual environment into ROS nodes unless the environment is deliberately tested. Preserve the apt/package snapshot or a restorable system image because Noetic is EOL.

## Hardware-free bringup

```bash
source /opt/ros/noetic/setup.bash
source ros1_ws/devel/setup.bash
roslaunch wildebeest_bringup robot.launch use_sim:=true
```

For a base-only checkout that exposes the lower-level mock argument:

```bash
roslaunch wildebeest_base base.launch mock:=true
```

Inspect the graph:

```bash
rosnode list
rostopic list
rostopic hz /wheel/odometry
rostopic hz /odometry/filtered
rostopic echo /diagnostics
rosrun tf tf_echo odom base_link
```

Confirm no physical serial process is running before injecting test commands.

## Physical base bringup

Complete H0–H2 and follow the same stable-device and current-limited stand procedure as ROS 2. Then:

```bash
source /opt/ros/noetic/setup.bash
source ros1_ws/devel/setup.bash
roslaunch wildebeest_bringup robot.launch \
  use_sim:=false base_port:=/dev/wildebeest-base sensors:=false joystick:=false
```

This first launch isolates the base. After each model-specific sensor and the selected teleoperation device passes its standalone test, enable only the required components in the full profile.

Inspect the exact launch API in the checkout:

```bash
roslaunch wildebeest_bringup robot.launch --args
```

Do not enable the motor branch until diagnostics, hand-turned encoder sign, reset handling, hard/software stops, and USB-pull watchdog behavior pass.

## Software stop and odometry reset

```bash
# Engage software stop
rosservice call /base/set_estop "data: true"

# Clear only after the physical scene is safe
rosservice call /base/set_estop "data: false"

# Reset host odometry while stationary, where the checked-out profile provides it
rosservice call /base/reset_odometry "{}"
```

`/base/reset_odometry` uses `std_srvs/Empty` and is optional where estimator state is authoritative. Service availability depends on the installed package revision. The physical E-stop is authoritative and cannot be cleared through ROS.

## ROS 1 networking

For a remote workstation, choose one reachable master, set hostnames/IPs consistently, and verify bidirectional connectivity. A common explicit layout is:

```bash
export ROS_MASTER_URI=http://<robot-host>:11311
export ROS_IP=<this-host-ip>
```

Do not set `ROS_HOSTNAME` and `ROS_IP` inconsistently. Test by echoing a small topic from each host, then inspect a high-bandwidth sensor separately. Isolate the network; anyone who can reach the ROS 1 graph may be able to publish motion commands or call services.

## Sensors and navigation

GPS, LiDAR and camera remain model-specific Jetson devices. Install only drivers compatible with Noetic and the exact vendor hardware. Validate each standalone before including it in bringup. `gscam` is not resolved by the current Noetic rosdep index, so the bootstrap deliberately skips it and the camera launch defaults to off. Install and validate a Jetson-compatible `gscam` build separately, then opt in with `camera:=true`; do not enable that launch flag merely because a camera frame exists in the URDF.

For mapping/navigation, prove `/scan`, `odom -> base_link`, URDF transforms, footprint, and stop paths before starting the navigation stack. Store real maps outside generated build directories and record their coordinate origin and environment revision.

The integrated launch makes transform ownership explicit: the local EKF owns
`odom -> base_link` while localization is enabled, and the base bridge owns it
only when localization is disabled. `mapping:=true` takes precedence over
`navigation:=true` if both are supplied, preventing GMapping and AMCL from
publishing `map -> odom` together.

## Migration to ROS 2

Prefer migrating packages and replayable tests over operating a permanent `ros1_bridge`. When a temporary bridge is necessary:

- consult the official compatibility matrix for an OS where both sides can be built;
- bridge only enumerated topics needed for the migration test;
- ensure there is still exactly one `/cmd_vel` and TF owner;
- never bridge software-stop semantics without an end-to-end failure test;
- record serialization, QoS and timestamp behavior;
- remove the bridge when native ROS 2 ownership is complete.

Ubuntu 24.04 does not support ROS 1, so the Jazzy workstation is not a drop-in host for a dynamic bridge.

## Definition of done

ROS 1 support means reproducible Noetic/20.04 builds and tests, protocol parity with firmware, hardware-free operation, and clearly labeled physical evidence. It does not mean ROS 1 is maintained upstream or safe to deploy on an open network.

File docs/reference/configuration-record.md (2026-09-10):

# Configuration record

Create one copy of this record per physical robot and released hardware/software combination. `TBD` means the robot has not passed commissioning for the affected function.

## Identity and provenance

| Field | Value |
|---|---|
| Robot ID / asset number | `TBD` |
| Hardware revision | `TBD` |
| Assembly date / technician | `TBD` |
| Repository commit/tag | `TBD` |
| Firmware build ID and compile-time options | `TBD` |
| ROS profile and distribution | `TBD` |
| Jetson module/carrier revision | `TBD` |
| JetPack/L4T and Ubuntu version | `TBD` |
| Storage image checksum/backup location | `TBD` |

## Safety and power

| Field | Value / evidence |
|---|---|
| Battery manufacturer/part/serial | `TBD` |
| Cell chemistry/configuration | 2S Li-ion stated by concept; exact pack `TBD` |
| BMS/protection specifications | `TBD` |
| Approved charger | `TBD` |
| Main fuse type/rating/rationale | `TBD` |
| Wire/connector rating rationale | `TBD` |
| Hard E-stop part and motor-energy interruption diagram | `TBD` |
| Compute rail voltage/current/transient/thermal validation | `TBD` |
| Motor rail envelope and peak current | `TBD` |
| Battery-divider values, tolerance analysis and scale factor | `TBD` |
| Undervoltage warning/stop thresholds and pack evidence | `TBD` |
| Maximum component/ambient temperature criteria | `TBD` |

## Geometry and drive

| Field | Repository initial value | Measured value / uncertainty / method |
|---|---:|---|
| Left effective wheel radius | 0.033622 m CAD baseline | `TBD` |
| Right effective wheel radius | 0.033622 m CAD baseline | `TBD` |
| Geometric wheel separation | 0.121843 m CAD baseline | `TBD` |
| Effective skid-steer separation | 0.121843 m initial setting | `TBD` |
| Front/rear wheelbase | 0.117150 m CAD baseline | `TBD` |
| Left counts/output revolution | 600 placeholder | `TBD` |
| Right counts/output revolution | 600 placeholder | `TBD` |
| Quadrature decode mode | `TBD` | `TBD` |
| Motor polarity | `TBD` | `TBD` |
| Encoder polarity | `TBD` | `TBD` |
| Total operating mass / payload | `TBD` | `TBD` |
| Center-of-gravity validation | `TBD` | `TBD` |
| Ground clearance | `TBD` | `TBD` |

## Software safety limits

| Field | Initial contract | Validated setting / evidence |
|---|---:|---|
| MCU command watchdog | 300 ms | `TBD` |
| MCU control target | 50 Hz | `TBD` |
| Maximum linear velocity | none implied | `TBD` |
| Maximum angular velocity | none implied | `TBD` |
| Linear/angular acceleration limits | none implied | `TBD` |
| Command-source timeouts/priorities | configuration-dependent | `TBD` |
| Motor current/temperature stop policy | hardware-dependent | `TBD` |
| Sensor freshness thresholds | sensor-dependent | `TBD` |

## Sensors

For every sensor, attach the exact datasheet and record supply, interface, identifier/device path, driver/version, update rate, frame, measured transform, calibration file/checksum, covariance basis, freshness threshold, and known degraded behavior.

| Sensor | Exact part | Interface/device | Frame | Calibration/evidence |
|---|---|---|---|---|
| Left encoder | `TBD` | D2/D4 default | wheel joint | `TBD` |
| Right encoder | `TBD` | D3/D12 default | wheel joint | `TBD` |
| MPU6050 breakout | `TBD` | A4/A5 I²C default | `imu_link` | `TBD` |
| Front HC-SR04 | `TBD` | D11/A0 default | `ultrasonic_front_link` | `TBD` |
| 2D LiDAR | `TBD` | Jetson direct, `TBD` | `lidar_link` | `TBD` |
| IMX219 camera/lens | `TBD` | Jetson CSI | `camera_optical_frame` | `TBD` |
| NEO-6M breakout/antenna | `TBD` | Jetson direct, `TBD` | `gps_link` | `TBD` |

## Network and operations

| Field | Value |
|---|---|
| Robot hostname | `TBD` |
| Network trust boundary | `TBD` |
| Time synchronization source and measured offset | `TBD` |
| ROS 1 master URI/network settings, if used | `TBD` |
| ROS 2 domain ID/RMW/discovery policy, if used | `TBD` |
| Log/bag retention location and capacity | `TBD` |
| Operator, spotter and test-zone requirements | `TBD` |
| Authorized operating surface/slope/weather/light | `TBD` |
| Startup/shutdown checklist revision | `TBD` |

Do not store Wi-Fi passwords, access tokens, private keys, or personal data in this repository. Reference the approved secret-management location instead.

## Acceptance sign-off

| Stage | Result | Date | Evidence link | Reviewer |
|---|---|---|---|---|
| H0 Documentation/design review | `NOT RUN` | | | |
| H1 Unpowered/rail validation | `NOT RUN` | | | |
| H2 Firmware and sensor bench | `NOT RUN` | | | |
| H3 Lifted-wheel motion | `NOT RUN` | | | |
| H4 Low-speed manual floor test | `NOT RUN` | | | |
| H5 Localization | `NOT RUN` | | | |
| H6 Simulation regression | `NOT RUN` | | | |
| H7 Supervised autonomous mission | `NOT RUN` | | | |
| H8 Endurance/thermal test | `NOT RUN` | | | |

Any safety-relevant hardware, firmware, calibration, limit, or launch change invalidates the affected sign-offs until regression tests are repeated.

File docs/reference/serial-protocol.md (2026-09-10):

# Serial protocol v1

The Jetson/workstation base bridge and Arduino use a small, bounded ASCII protocol. It is designed to reject malformed motion commands and recover framing after line noise. It is **not** a substitute for the hard-wired motor emergency stop.

Normative implementations are:

- firmware: `firmware/wildebeest_base/include/Protocol.h` and `src/main.cpp`;
- host reference codec: `tools/wildebeest_protocol.py`;
- ROS bridge codecs under each workspace's `wildebeest_base` package.

If those implementations disagree, stop hardware testing and resolve the contract plus cross-language vectors first.

## Physical link

| Property | Value |
|---|---|
| Transport | USB serial to Arduino Uno |
| Format | 115200 baud, 8 data bits, no parity, 1 stop bit (8-N-1) |
| Encoding | 7-bit ASCII fields and hexadecimal CRC; newline terminated |
| Flow control | None |
| Maximum frame | 128 bytes including the terminating `\n` |
| Firmware receive capacity | 128 bytes: at most 127 stored bytes before `\n`, leaving room for the internal null terminator |

Use a stable `/dev/serial/by-id/...` path or a narrowly matched udev symlink. Device enumeration names such as `/dev/ttyACM0` are not stable across reconnects.

The protocol provides integrity against accidental corruption, not authentication or encryption. Treat physical USB access and the host account as privileged control access; do not tunnel the raw port over an untrusted network.

## Frame grammar

```text
@TYPE,sequence[,field...]*CCCC\n
```

- `@` begins and re-synchronizes a frame.
- `TYPE` is the uppercase message type.
- `sequence` is a canonical unsigned decimal integer from `0` through `65535`; wrap to zero is normal.
- Fields are comma-separated canonical decimal integers unless a message says otherwise.
- `*` ends the CRC input.
- `CCCC` is exactly four hexadecimal digits for CRC-16/CCITT-FALSE over the bytes strictly between `@` and `*`.
- `\n` ends the line; receivers may ignore `\r` for CRLF interoperability.

CRC parameters:

| Parameter | Value |
|---|---:|
| Width | 16 bits |
| Polynomial | `0x1021` |
| Initial value | `0xFFFF` |
| Input/output reflection | false |
| Final XOR | `0x0000` |
| Check value for ASCII `123456789` | `0x29B1` |

Known vector:

```text
@PING,42*F43D
```

CRC letters emitted by the firmware are uppercase. Parsers may accept lowercase hex, but generated test vectors use uppercase.

## Host-to-controller messages

### `CMD`

```text
@CMD,<sequence>,<linear_mm_s>,<angular_mrad_s>*<crc>\n
```

| Field | Unit | Firmware v1 accepted range |
|---|---:|---:|
| `linear_mm_s` | mm/s | -450 to +450 |
| `angular_mrad_s` | mrad/s | -1800 to +1800 |

Positive linear velocity is forward. Positive angular velocity is counter-clockwise viewed from above, matching ROS. The controller converts body command to left/right wheel targets using its configured radius and separation.

A valid in-range `CMD` refreshes the firmware watchdog. A bad CRC, bad schema, unknown type, or out-of-range value does not. The host sends commands continuously while motion is authorized; the firmware stops motor output after 300 ms without a valid `CMD`.

Values outside the firmware limits are rejected rather than clamped. ROS-side limits should be equal or more conservative. These firmware values are initial prototype ceilings, not authorization to operate at that speed.

### `PING`

```text
@PING,<sequence>*<crc>\n
```

The controller replies immediately with `PONG` using the same sequence. A successful ping proves framing/round-trip communication, not fresh odometry or safe motor state.

### `ESTOP`

```text
@ESTOP,<sequence>,<state>*<crc>\n
```

`state=1` engages the software stop and zeros requested targets. Either state
transition invalidates the previous motion command. Opening the physical
hard-stop sense loop also engages the software latch, so releasing the physical
button cannot restart a continuously publishing host. Only after the physical
loop is healthy may `state=0` clear the software latch, and a fresh valid `CMD`
is still required for motion. On ROS bridge shutdown, the expected sequence is
zero command followed by software-stop engage, then port close.

Never use this message as the sole emergency stop. USB, Linux, a process, and the MCU can all fail.

## Controller-to-host messages

All telemetry message types share one wrapping 16-bit controller sequence counter. A gap can indicate dropped/corrupt frames, but `PONG` and `ERR` echo host sequences and therefore are not part of that telemetry sequence stream.

### `BOOT`

```text
@BOOT,0,WILDEBEEST_BASE,1*<crc>\n
```

Sent at controller startup. The final field is protocol version `1`. Receiving `BOOT` means counts and controller state may have reset. The host must invalidate stale integration state, keep motion stopped, and require deliberate recovery.

### `ODOM`

```text
@ODOM,<sequence>,<left_ticks>,<right_ticks>,<left_mrad_s>,<right_mrad_s>,<battery_mv>,<flags>*<crc>\n
```

| Field | Meaning |
|---|---|
| `left_ticks`, `right_ticks` | Signed absolute counts since the current MCU boot, using the configured ISR decode mode |
| `left_mrad_s`, `right_mrad_s` | Signed measured output-wheel angular velocities in milliradians/second |
| `battery_mv` | Filtered ADC estimate, accepted from `0` through `20000` mV; meaningful only after divider/reference calibration |
| `flags` | Unsigned status bit mask below |

Default target rate is 20 Hz. Host odometry uses the configured counts/revolution and wheel geometry. A controller reset or implausible tick jump must never become a huge pose increment.

### `IMU`

```text
@IMU,<sequence>,<ax_mg>,<ay_mg>,<az_mg>,<gx_mdps>,<gy_mdps>,<gz_mdps>*<crc>\n
```

Acceleration fields are milli-g; angular-rate fields are millidegrees/second. The host converts to SI. Default target rate is 50 Hz when the MPU6050 compile-time option is enabled and initialization succeeds. The frame carries no calibrated orientation, covariance, temperature, or sensor timestamp; the ROS publisher must represent those limitations honestly.

### `RANGE`

```text
@RANGE,<sequence>,<front_mm>*<crc>\n
```

Hosts accept `front_mm` from `0` through `2000`. Successful physical HC-SR04
measurements are clamped to `20..2000` mm and reported at a target rate of
10 Hz. On echo timeout, firmware sets the range-timeout flag and omits a new
`RANGE` sample. The host must age out the previous range rather than treating
it as current or obstacle-free. A value below the configured ROS sensor minimum
is represented conservatively as negative infinity (object too close), not as
clear space.

### `PONG`

```text
@PONG,<host_sequence>*<crc>\n
```

Echoes the triggering `PING` sequence.

### `ERR`

```text
@ERR,<host_sequence>,<code>*<crc>\n
```

Current codes are:

| Code | Meaning |
|---|---|
| `RANGE` | A `CMD` field was missing, noncanonical, or outside firmware range |
| `SCHEMA` | An `ESTOP` field/count was invalid |
| `TYPE` | The frame type was unknown or otherwise unmatched |

Frames that fail outer framing/CRC may not yield an `ERR`, because their sequence cannot be trusted. A transient protocol-error status flag is set locally.

An `ERR` frame or an `ODOM` frame carrying that protocol-error flag is a
fail-closed event. The host latches its software stop, discards command
freshness, closes the transport, and will not authorize motion until a new
connection supplies the exact supported `BOOT,0,WILDEBEEST_BASE,1` identity.

## Status flags

| Bit | Mask | Name | Effect/meaning |
|---:|---:|---|---|
| 0 | `0x0001` | command watchdog | Blocking: no recent valid `CMD` |
| 1 | `0x0002` | hard E-stop | Blocking: fail-safe A1 sense loop is open/`HIGH` (pressed, unplugged, or broken) |
| 2 | `0x0004` | software E-stop / re-arm latch | Blocking: `ESTOP,1` or a physical hard-stop event latched a deliberate re-arm requirement |
| 3 | `0x0008` | protocol error | A malformed/rejected frame was observed; currently transient |
| 4 | `0x0010` | IMU error | MPU6050 unavailable or read failed |
| 5 | `0x0020` | range timeout | HC-SR04 acquisition timed out |
| 6 | `0x0040` | low battery | ADC estimate is at/below the configured warning threshold |

Bits 0–2 prevent motor motion. Low-voltage motor stopping is compile-time
configurable and is disabled by default until the divider and pack thresholds
are commissioned. If enabled, it uses `BATTERY_STOP_MV`, not the warning flag,
and releases only after `BATTERY_STOP_HYSTERESIS_MV` of recovery. The initial
unverified values are 6600 mV and 150 mV respectively. Either cutoff transition
invalidates command freshness. The electrical BMS/protection remains
authoritative.

Unknown flag bits must be preserved in diagnostics and treated conservatively. They must not be silently masked as healthy.

## Receiver requirements

A compliant receiver:

1. bounds memory use and frame length;
2. drops bytes until `@`, and re-synchronizes if a new `@` appears;
3. verifies the full CRC before parsing fields;
4. rejects unknown type, wrong field count, whitespace/noncanonical integers, overflow, and out-of-range fields;
5. never refreshes the motion watchdog for an invalid message;
6. tracks invalid/dropped frames in diagnostics;
7. detects telemetry gaps, staleness, reset/`BOOT`, and reconnect;
8. converts units only after validation;
9. sends zero and software E-stop during orderly shutdown where the link remains available.

## Compatibility and change control

Protocol v1 is deliberately not self-describing beyond the `BOOT` version. Adding an optional field to an existing message breaks strict parsers. To change a schema or unit:

- increment the protocol version;
- update firmware, tools, both ROS bridges, mock controller, tests, and this page atomically;
- keep golden vectors for every message and invalid boundary;
- verify old/new mismatch fails stopped rather than partially working;
- record the firmware protocol version in diagnostics and bag metadata.

## Bench verification

With motor power physically removed:

```bash
# Pure codec/mock tests; no serial hardware required
python3 -m unittest discover -s tools/tests -v

# Inspect the deterministic demo stream
python3 tools/mock_mcu.py --demo --seconds 2
```

Then use the actual MCU to prove CRC rejection, range rejection, sequence wrap, reset handling, cable removal, 300 ms watchdog, hard/soft stop priority, and recovery. Capture raw serial logs without secrets and link them to the acceptance record.

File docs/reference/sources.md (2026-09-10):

# Documentation sources

Project guidance distinguishes upstream facts from robot-specific assumptions. Consult the current upstream page before changing an OS image, ROS distribution, driver, or safety-relevant component.

## ROS and platform sources

- [ROS 1 Noetic end-of-life notice](https://www.ros.org/blog/noetic-eol/) — Noetic/ROS 1 support ended on 31 May 2025.
- [ROS 2 Jazzy Ubuntu installation](https://docs.ros.org/en/jazzy/Installation/Ubuntu-Install-Debs.html) — the repository's reference ROS 2 profile uses Jazzy on Ubuntu 24.04.
- [ROS 2 Jazzy release/platform information](https://docs.ros.org/en/jazzy/Releases/Release-Jazzy-Jalisco.html) — authoritative platform and support details.
- [ROS 1 bridge compatibility](https://docs.ros.org/en/humble/p/ros1_bridge/index.html) — co-installation and operating-system constraints.
- [REP-105 coordinate frames](https://www.ros.org/reps/rep-0105.html) — `map`, `odom`, and `base_link` semantics.
- [ROS 2 `diff_drive_controller`](https://control.ros.org/jazzy/doc/ros2_controllers/diff_drive_controller/doc/userdoc.html) — wheel feedback, velocity commands, odometry, limits, and timeout behavior.
- [`robot_localization` documentation](https://docs.ros.org/en/noetic/api/robot_localization/html/index.html) — odometry/IMU fusion and GNSS transformation concepts.
- [NVIDIA JetPack 4.6 archive](https://developer.nvidia.com/embedded/jetpack-sdk-46) — Jetson Nano generation-specific software resources.

## Component evidence required locally

Before hardware commissioning, archive the exact manufacturer's documentation or distributor traceability for:

- Jetson Nano module and carrier board;
- Arduino-compatible board;
- motor and gearbox;
- encoder or KY-040-style module;
- L298N carrier board;
- MPU6050 breakout;
- NEO-6M GNSS breakout and antenna;
- exact LiDAR model;
- exact IMX219 camera module;
- HC-SR04 modules;
- battery cells, holder/pack, BMS/protection board, and charger;
- buck regulator(s), fuse, switch, E-stop, connectors, and wire.

A CAD filename, marketplace title, silkscreen color, or family name is not a datasheet. Record document revision and a local checksum or durable URL in the [configuration record](configuration-record.md).

## Updating this handbook

When an upstream link changes, update the link and the associated compatibility claim in the same pull request. Do not silently change a tested platform profile to follow the newest ROS release; add and validate a new profile first.

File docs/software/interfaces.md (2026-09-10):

# ROS interface contract

This is the stable, version-neutral contract between Wildebeest Pro packages. ROS 1 uses `package/Message`; ROS 2 uses `package/msg/Message`, but field semantics, units, frames, and ownership remain the same.

## Command path

| Interface | Type | Publisher | Subscriber | Contract |
|---|---|---|---|---|
| `/cmd_vel` | `geometry_msgs/Twist` | velocity multiplexer | `wildebeest_base` | Selected base command; only `linear.x` and `angular.z` are supported |
| Raw teleop input | `geometry_msgs/Twist` | joystick/keyboard teleop | velocity multiplexer | Topic name is launch-configured; must not bypass arbitration |
| Raw navigation input | `geometry_msgs/Twist` | navigation controller | velocity multiplexer | Topic name is launch-configured; stale input times out |
| `/wildebeest/estop` | `std_msgs/Bool` | dashboard/safety UI | velocity multiplexer and base bridge | `true` engages/locks the software stop; `false` is only a release request |

The public `/cmd_vel` owner is the multiplexer. A launch configuration without a multiplexer may connect a single test source directly, but that mode must be conspicuously named and must retain the MCU watchdog. Unsupported Twist axes are ignored, never mapped to another behavior.

Control services use `/base/set_estop` (`std_srvs/SetBool`) and, where implemented, `/base/reset_odometry` (`std_srvs/Empty`). Reset odometry only while stationary. Software topic/service controls never release the physical E-stop and resetting a latch must not itself create motion.

## Base feedback

| Interface | Type | Frame(s) | Nominal source |
|---|---|---|---|
| `/wheel/odometry` | `nav_msgs/Odometry` | header `odom`, child `base_link` | `wildebeest_base`; raw encoder integration |
| `/odometry/filtered` | `nav_msgs/Odometry` | header `odom`, child `base_link` | designated local encoder/IMU estimator |
| `/joint_states` | `sensor_msgs/JointState` | joint names from URDF | `wildebeest_base` |
| `/battery_state` | `sensor_msgs/BatteryState` | n/a | `wildebeest_base`; meaningful only after ADC calibration |
| `/tf` | `tf2_msgs/TFMessage` | dynamic `odom -> base_link` | exactly one configured owner, normally the local estimator |
| `/diagnostics` | `diagnostic_msgs/DiagnosticArray` | n/a | base and sensor drivers |

`/odom` is reserved as an optional compatibility or simulator remap. It is not canonical and must never create a second odometry/TF owner. Raw and filtered odometry are continuous but may drift; they must not jump when a global localization correction arrives. Covariance values must be measured/tuned; arrays of all zeros falsely claim perfect certainty.

## Sensor topics

| Interface | Type | Required frame | Notes |
|---|---|---|---|
| `/imu/data_raw` | `sensor_msgs/Imu` | `imu_link` | Raw angular velocity and linear acceleration; orientation covariance starts with `-1` when no orientation estimate exists |
| `/range/front` | `sensor_msgs/Range` | `ultrasonic_front_link` | Radiation type, field of view, min/max range come from the exact module characterization |
| `/scan` | `sensor_msgs/LaserScan` | `lidar_link` | Model-specific driver; verify scan order, zero angle, range limits, and timestamp |
| `/camera/image_raw` | `sensor_msgs/Image` | `camera_optical_frame` | Use image transport where available |
| `/camera/camera_info` | `sensor_msgs/CameraInfo` | same optical frame | Must match resolution and calibration of the image stream |
| `/gps/fix` | `sensor_msgs/NavSatFix` | `gps_link` | Preserve driver status and covariance; no fix is not zero latitude/longitude |

Additional ultrasonic sensors use explicit location names such as `/range/left`; each requires a matching fixed frame and a documented crosstalk schedule.

## Fused-state topics

Canonical names are:

- `/wheel/odometry` — raw encoder-integrated odometry from the base bridge;
- `/odometry/filtered` — local encoder/IMU estimate;
- `/odometry/gps` — GNSS transformed into the world frame when configured;
- `/imu/data` — filtered/estimated orientation only if a component truly produces it.

Do not feed the same physical measurement twice—for example, both wheel odometry pose and a twist derived from those same ticks—without accounting for their correlation. GNSS fusion requires a valid heading strategy and plausible covariance. The `robot_localization` package can fuse odometry and IMU and transform GNSS fixes, but its configuration is not self-calibrating.

## Topic ownership rules

At runtime, audit the graph against these invariants:

1. Exactly one selected `/cmd_vel` publisher feeds the base.
2. Exactly one node owns `odom -> base_link`.
3. Exactly one node owns `map -> odom`.
4. One `robot_state_publisher` owns fixed robot transforms.
5. Each wheel joint appears once in `/joint_states`.
6. Every sensor message has a frame reachable from `base_link`.
7. Simulation and hardware drivers are mutually exclusive for a given interface.

Useful checks:

=== "ROS 2"

    ```bash
    ros2 topic info /cmd_vel --verbose
    ros2 topic info /wheel/odometry --verbose
    ros2 topic hz /wheel/odometry
    ros2 topic hz /odometry/filtered
    ros2 run tf2_tools view_frames
    ros2 run tf2_ros tf2_echo odom base_link
    ```

=== "ROS 1"

    ```bash
    rostopic info /cmd_vel
    rostopic info /wheel/odometry
    rostopic hz /wheel/odometry
    rostopic hz /odometry/filtered
    rosrun tf2_tools view_frames.py
    rosrun tf tf_echo odom base_link
    ```

## ROS 2 QoS policy

Default QoS must match the producer and consumer. As a starting contract:

| Data class | Reliability | Durability | Queue intent |
|---|---|---|---|
| Velocity command | reliable | volatile | shallow; latest command matters |
| Odometry/joints/IMU | best effort or reliable by measured link quality | volatile | bounded, small |
| LiDAR/camera | sensor-data profile (typically best effort) | volatile | avoid accumulating stale frames |
| Robot description/static metadata | reliable | transient local where the component expects it | late joiners receive state |
| Diagnostics | reliable | volatile | bounded |

Do not change reliability simply to hide packet loss. Measure resource use and end-to-end age, particularly over Wi-Fi.

## Parameters that must be recorded

| Parameter | Unit | Initial repository value | Commissioning requirement |
|---|---:|---:|---|
| Wheel radius | m | `0.033622` | CAD-derived starting value; measure under operating load |
| Effective wheel separation | m | `0.121843` | CAD geometric track; tune skid-steer behavior from repeated turns |
| Wheelbase | m | `0.117150` | CAD-derived front/rear wheel-centre spacing; verify physically |
| Encoder counts/revolution | counts/output-shaft revolution | `600` | Placeholder; identify decode mode and measure |
| Command watchdog | ms | `300` | Verify with scope/video and timestamped logs |
| Firmware control rate | Hz | `50` | Verify under maximum telemetry load |
| Odom publication target | Hz | `20` | Verify observed rate/jitter |
| IMU publication target | Hz | `50` | Optional at compile time; verify if enabled |
| Range publication target | Hz | `10` | Verify no ultrasonic crosstalk |

Robot-specific velocity, acceleration, jerk, current, voltage, and temperature limits are intentionally `TBD`. Set them from component evidence and controlled testing, not from example robot values.

## Namespaces and multi-robot use

For a single robot, the absolute topic names above keep examples simple. Multi-robot deployments must namespace topics and frame IDs consistently (for example `wb01/...`) while preserving REP-105 topology. Never put two robots on one ROS graph with both publishing unprefixed `odom -> base_link`.

## Compatibility promise

A change is interface-breaking if it changes a topic name, message type, unit, sign convention, frame, joint name, serial field meaning, or watchdog behavior. Such a change requires:

- a documented migration note;
- synchronized ROS 1, ROS 2, firmware, simulation, and documentation updates;
- new protocol/version handling where applicable; and
- replay or integration tests covering the old failure mode.

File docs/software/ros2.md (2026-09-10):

# ROS 2 Jazzy

The maintained ROS 2 profile targets **ROS 2 Jazzy on Ubuntu 24.04**. For Wildebeest Pro's Jetson Nano generation, treat this as a workstation/split-compute reference: a stock JetPack 4 Nano image cannot natively provide the supported Jazzy/24.04 environment. Hardware deployment requires a separately validated transport and device-driver architecture.

!!! warning "Support boundary"
    The ROS graph, mock controller, description, and simulation can be validated on a supported workstation. That does not validate a particular Jetson image, CSI camera path, LiDAR model, serial permissions, Arduino harness, or motor system. Do not replace the Nano OS merely to make an install command pass without a recovery image and camera/GPU validation plan.

## Packages

| Package | Contents |
|---|---|
| `wildebeest_description` | Xacro/URDF, meshes, sensor and wheel frames, RViz configuration |
| `wildebeest_base` | Checksummed Arduino bridge, mock transport, wheel odometry, joint/IMU/range topics, diagnostics and stop services |
| `wildebeest_bringup` | Integrated description/base/sensor/localization/teleop/twist-mux launch |
| `wildebeest_navigation` | Nav2, SLAM Toolbox, maps and navigation RViz configuration |
| `wildebeest_gz` | Gazebo Sim/Harmonic world, spawn and ROS bridges |

## Install the ROS environment

Install Jazzy using the official [Ubuntu deb-package instructions](https://docs.ros.org/en/jazzy/Installation/Ubuntu-Install-Debs.html). Confirm the host reports Ubuntu 24.04 and source the ROS environment:

```bash
source /opt/ros/jazzy/setup.bash
printenv ROS_DISTRO
```

The result must be `jazzy`. Do not source ROS 1 and ROS 2 environments into the same shell unless deliberately building a supported bridge environment.

## Bootstrap and build

From the repository root:

```bash
./scripts/bootstrap.sh ros2
./scripts/build.sh ros2
source ros2_ws/install/setup.bash
```

The bootstrap script resolves declared dependencies; review it before allowing package installation. To reproduce the underlying build manually:

```bash
source /opt/ros/jazzy/setup.bash
rosdep install --from-paths ros2_ws/src --ignore-src -r -y --rosdistro jazzy
cd ros2_ws
colcon build --symlink-install
source install/setup.bash
colcon test --event-handlers console_direct+
colcon test-result --verbose
```

Do not run `colcon` or the workspace as root. If a package is unavailable, record the exact OS architecture, repository sources, and `rosdep` error; do not substitute a package for another ROS distribution.

## Hardware-free bringup

Use mock mode before connecting the Arduino:

```bash
source /opt/ros/jazzy/setup.bash
source ros2_ws/install/setup.bash
ros2 launch wildebeest_bringup robot.launch.py use_sim:=true
```

If the integrated launch exposes transport directly in the checked-out revision, the equivalent base-only smoke test is:

```bash
ros2 launch wildebeest_base base.launch.py transport:=mock
```

In another terminal:

```bash
source /opt/ros/jazzy/setup.bash
source ros2_ws/install/setup.bash
ros2 node list
ros2 topic list
ros2 topic hz /wheel/odometry
ros2 topic hz /odometry/filtered
ros2 topic echo /diagnostics
ros2 run tf2_ros tf2_echo odom base_link
```

Before publishing a nonzero command, confirm mock/simulation mode and that no physical base bridge owns `/cmd_vel`.

## Physical base bringup

Complete hardware acceptance stages H0–H2 first. Lift and restrain the robot, remove or open the motor-power branch, and keep the hard E-stop asserted.

### Stable serial identity

Inspect the actual device:

```bash
ls -l /dev/serial/by-id/
udevadm info --attribute-walk --name=<actual-tty-device>
```

Create a udev rule only from attributes unique to the installed Arduino. A generic vendor/product rule may capture another board. A narrowly matched example is shown in the `wildebeest_base` package README; replace every placeholder and review the resulting permissions. Prefer group access such as `dialout`, not world-writable devices.

### Launch

```bash
source /opt/ros/jazzy/setup.bash
source ros2_ws/install/setup.bash
ros2 launch wildebeest_bringup robot.launch.py \
  use_sim:=false transport:=serial serial_port:=/dev/wildebeest-base
```

Launch arguments are revision-controlled API. Use `--show-args` to inspect the checkout:

```bash
ros2 launch wildebeest_bringup robot.launch.py --show-args
```

Keep motor power disconnected until all of these are true:

- `BOOT`/protocol version accepted;
- base diagnostics identify a live controller with watchdog active;
- encoder ticks change with correct sign when wheels are turned by hand;
- IMU axes and range timeout behavior are plausible;
- battery sensing is either physically absent/disabled or calibrated and safe;
- TF has one owner per edge;
- software-stop service engages, and clearing it does not create motion;
- pulling USB leaves outputs stopped by the 300 ms MCU watchdog.

## Services

The base package exposes deliberate control services:

```bash
# Engage software stop
ros2 service call /base/set_estop std_srvs/srv/SetBool "{data: true}"

# Clear software stop only after the physical scene is safe
ros2 service call /base/set_estop std_srvs/srv/SetBool "{data: false}"

# Reset host-integrated odometry while stationary
ros2 service call /base/reset_odometry std_srvs/srv/Empty "{}"
```

The reset service is optional in profiles where estimator state is authoritative; check `ros2 service list -t`. The hard E-stop is never cleared through ROS. After any stop/reset, require a fresh command source and verify diagnostics before motion.

## Sensor integration

GPS, LiDAR, and camera connect to the Jetson/sensor computer, not the Arduino protocol. Their launch is model-specific and should be disabled by default until exact drivers and device parameters are configured.

For each driver:

1. launch it alone;
2. verify device identity and permissions;
3. inspect rate, timestamp age, frame, units, covariance and disconnect behavior;
4. validate its static transform;
5. then enable it in `wildebeest_bringup`.

An IMX219 on Jetson normally depends on NVIDIA's CSI/Argus stack rather than a generic USB-camera assumption. Preserve the working JetPack camera pipeline on the Nano and bridge images only through a measured, explicitly designed method if ROS 2 runs on another computer.

## Localization

Start with encoder/IMU local odometry. The base publishes raw IMU data; configure the estimator only for measurements truly present. The MPU6050 does not provide absolute yaw. Validate covariances and TF ownership before adding LiDAR SLAM or GNSS.

In integrated bringup, the local EKF is the single `odom -> base_link` owner.
If `start_localization:=false` is deliberately selected, the base bridge
automatically becomes the single owner instead; do not start a second source.

GNSS integration typically requires `/gps/fix`, a local odometry estimate, and a valid earth-referenced heading strategy. A stationary NEO-6M fix plus gyro integration does not meet that requirement by itself.

## Mapping and navigation

With base, TF, `/scan`, and safety behavior proven:

```bash
# Create a map
ros2 launch wildebeest_navigation navigation.launch.py slam:=true

# Localize/navigate using a reviewed real map
ros2 launch wildebeest_navigation navigation.launch.py slam:=false \
  map:=<absolute-path-to-map-yaml>
```

Any included map is a configuration example, not a valid map of the user's environment. Before enabling Nav2 motion, validate footprint, inflation radius, transform tolerances, sensor range/clearing behavior, velocity/acceleration limits, recovery behaviors, and command-multiplexer priority.
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

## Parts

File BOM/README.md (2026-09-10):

# Bill of materials

[`Wildebeest_Pro_BOM.xlsx`](Wildebeest_Pro_BOM.xlsx) is the working hardware and
commissioning record. Filter by subsystem or status, enter supplier costs in the
yellow cells, and move a line to **Verified** only after inspecting or measuring
the actual part.

The drive rows reflect the audited four-wheel skid-steer assembly: four geared
motors and four wheels, with front/rear motors paired by side. The L298N remains
a blocker until each channel is proven against the combined side-pair current.

The workbook intentionally opens with a **BLOCKED** release gate. The original
concept did not identify several safety-critical selections: cell specification,
2S BMS, fuse, physical E-stop contacts, power distribution, motor stall current,
proper wheel encoders and the custom LiDAR interface. Resolve those rows before
powered floor testing.

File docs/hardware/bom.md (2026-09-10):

# Bill of materials

This is a functional BOM, not a purchasing guarantee. The original CAD includes recognizable module models, but marketplace modules with the same name often differ electrically and mechanically. Record manufacturer part numbers and verify the actual items before ordering mates, machining parts, or applying power.

## Core compute and control

| Qty | Item | Minimum selection evidence | Status to record |
|---:|---|---|---|
| 1 | NVIDIA Jetson Nano developer kit/module + carrier | Exact module/carrier revision, supported OS/JetPack, power input, CSI connector, cooling | `TBD` |
| 1 | Compatible storage medium | Capacity, endurance, image/backup method | `TBD` |
| 1 | Arduino Uno or pin-compatible 5 V MCU board | Board revision, USB interface, ADC reference behavior, I/O current limits | `TBD` |
| 1 | USB data cable, Jetson to Arduino | Data-capable, locking/strain-relieved where possible | `TBD` |
| 1 | Active cooling solution for Jetson | Supply, control method, clearance, verified airflow | CAD shows an NF-A4x20-class fan; actual part `TBD` |

## Drive and odometry

| Qty | Item | Minimum selection evidence | Notes |
|---:|---|---|---|
| 4 | Brushed DC geared motor | Voltage range, no-load and stall current, gear ratio, shaft, mounting | Matched units; front/rear motors are paired by side |
| 4 | Drive wheel | Measured loaded rolling radius, hub/shaft fit, tire material | CAD nominal radius is `0.033622 m`; verify under load |
| 2 minimum | Quadrature encoder | Supply, output type/level, counts definition, max edge rate | At least one observed wheel per side; repository default `600` counts/rev is a placeholder |
| 1 | L298N dual H-bridge module | Actual schematic, current/thermal behavior, logic arrangement, voltage drop | Each channel carries a same-side motor pair; verify combined stall current or replace the driver |
| 1 set | Motor/encoder connectors and harness | Current rating, keying, strain relief, flex life | Keep encoder wiring away from motor leads |

### L298N limitation

The L298N is an older bipolar-transistor driver with significant voltage drop and heat dissipation compared with modern MOSFET bridges. A red breakout board is not a current rating. Each channel must carry the combined load of two same-side motors in this four-wheel layout. Measure individual and paired stall current, driver temperature, loaded rail voltage, and duty cycle. If the driver cannot meet the verified envelope with margin, replace it with a protected driver sized for the paired load and update firmware polarity, wiring, BOM, tests, and CAD.

## Sensors

| Qty | Item | Interface to target | Evidence required |
|---:|---|---|---|
| 1 | MPU6050 IMU breakout | Arduino I²C | Breakout supply and pull-up topology, address, axis orientation |
| 1 | NEO-6M GNSS breakout + antenna | Jetson via verified USB/UART adapter | Supply and logic level, baud, update rate, antenna requirements |
| 1 | 2D LiDAR | Jetson, normally USB or serial | Exact model, driver, scan rate, supply/current, connector and mount |
| 1 | IMX219 camera + ribbon | Jetson CSI | Carrier compatibility, ribbon pin count/orientation, supported modes |
| 1 default | HC-SR04 ultrasonic module | Arduino trigger/echo | Exact module behavior, min/max useful range, beam and temperature effects |

The firmware reference pinout provides one front ultrasonic channel. More modules require an explicitly designed acquisition schedule and additional I/O or a secondary controller; do not parallel echo outputs.

## Power and protection

| Qty | Item | Selection/verification requirement |
|---:|---|---|
| 1 | Protected 2S Li-ion battery pack | Traceable cells; pack/BMS configuration; continuous/peak current; temperature limits; physical protection |
| 1 | Charger approved for the exact pack chemistry/configuration | Connector/polarity keyed differently from the load where practical |
| 1 | Main service disconnect | Rated for pack fault current and DC interruption |
| 1 | Branch fuse and holder | Rating derived from conductor, connector, driver, and expected load; mounted near energy source |
| 1 | Latching emergency-stop/disconnect assembly | Interrupts motor energy; optionally provides a separate dry contact for MCU status |
| 1+ | DC-DC buck regulator | Input range covers pack envelope; output accuracy, transient response, continuous current, thermal margin |
| as designed | Additional branch fuses/protection | Separate compute/sensor and actuator faults where the design permits |
| 1 | Battery-voltage divider/filter for Arduino A2 | Resistors sized for the **maximum possible pack voltage** and ADC pin limit; documented ratio and tolerance |
| 1 | Fire-resistant battery enclosure/retention | Prevents abrasion, crushing, puncture, shorting, and ejection |

!!! danger "The CAD battery model is not a battery design"
    A cell-holder model or capacity printed in a filename does not prove cell authenticity, safe parallel/series construction, balancing, protection, or charge compatibility. Do not assemble loose cells into a traction pack without the required battery-design competence and equipment. Prefer a professionally assembled, protected pack with traceable documentation.

## Structure and integration

- Base, top and bottom covers
- Motor mounts and encoder supports
- LiDAR, camera, ultrasonic and GNSS mounts
- Correct fasteners, washers, thread retention and spacers
- Insulating standoffs and guards for circuit boards and terminals
- Cable clips, abrasion protection, strain relief and service loops
- Wheel/shaft retention and guards around pinch points
- Clearly labeled main disconnect, emergency stop, charge port and polarity

The source SolidWorks assembly and STEP exports are reference geometry. Before fabrication, check units, material, tolerances, fastener lengths, tool access, cooling clearance, center of gravity, ground clearance, sensor field of view, and cable bend radius.

## Workshop and commissioning equipment

These are part of a safe build even though they remain off-robot:

- current-limited bench supply suitable for each rail;
- calibrated digital multimeter and, ideally, oscilloscope/logic analyzer;
- approved battery charger and fire-conscious charging/storage arrangement;
- insulated hand tools, ferrule/crimp tooling matched to terminals, and wire labels;
- nonconductive robot stand that leaves all four drive wheels free;
- USB isolator only if it is explicitly compatible with the test arrangement;
- tachometer or reliable wheel-revolution reference;
- scale/tape/calipers, level, marked floor course and camera calibration target;
- thermometer or thermal camera for driver/regulator/compute thermal checks.

## Power-budget worksheet

Complete this from datasheets and measurements. Do not size a regulator from typical current alone.

| Load | Rail | Idle | Sustained worst case | Startup/transient | Source evidence |
|---|---:|---:|---:|---:|---|
| Jetson + storage + fan | `TBD` | `TBD` | `TBD` | `TBD` | `TBD` |
| LiDAR | `TBD` | `TBD` | `TBD` | `TBD` | `TBD` |
| Camera | `TBD` | `TBD` | `TBD` | `TBD` | `TBD` |
| Arduino + IMU + sonar | `TBD` | `TBD` | `TBD` | `TBD` | `TBD` |
| Left motor | motor rail | `TBD` | `TBD` | stall `TBD` | `TBD` |
| Right motor | motor rail | `TBD` | `TBD` | stall `TBD` | `TBD` |

For each regulator/branch, document:

```text
continuous margin = rated continuous output under installed cooling - measured sustained load
transient margin  = validated transient capability - measured startup/step load
thermal margin    = component limit - worst observed component temperature
```

Ratings require the installed airflow and ambient-temperature envelope. A regulator that works uncovered on a bench may overheat inside the robot.

## Release BOM rule

A reproducible hardware release includes a machine-readable BOM with part number, manufacturer, supplier, quantity, approved substitutes, lifecycle status, datasheet revision, and the robot hardware revision it applies to. Substitutes that affect voltage, logic, geometry, driver software, calibration, or safety are engineering changes—not purchasing equivalents.

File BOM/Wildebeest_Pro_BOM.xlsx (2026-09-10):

Wildebeest Pro — hardware BOM and commissioning tracker
Concept-derived inventory. Yellow cells require builder input; every electrical rating and measured dimension must be verified before powered motion.
Required lines |  | Verified lines |  | Known subtotal (USD) |  | Release gate
25 |  | 0 |  | $0.00 |  | BLOCKED
POWER SAFETY: use a fused pack with a correctly rated 2S BMS and a physical E-stop that removes motor energy. Do not power motors from the Jetson or Arduino regulator.
ID | Subsystem | Component | Qty | Requirement | Reference / part | Interface / rail | Key requirement | Lifecycle | Verification status | Unit cost (USD) | Extended cost (USD) | Commissioning action
CMP-001 | Compute | Jetson Nano developer kit | 1 | Required | NVIDIA Jetson Nano; exact module TBD | 5 V regulated; USB; CSI | Confirm module/revision, storage, thermals and supported OS image | Concept hardware | Verify |  |  | Record board revision and sustained-load power draw
CMP-002 | Compute | High-endurance microSD or supported storage | 1 | Required | 64 GB minimum recommended; brand TBD | Jetson storage | Use high-endurance media; size for ROS bags and container images | Add | TBD |  |  | Select media and run read/write verification
CMP-003 | Compute | Active cooling fan | 1 | Required | Noctua NF-A4x20 5 V appears in CAD; verify | 5 V logic rail | Maintain Jetson temperature without back-feeding a GPIO header | CAD asset | Verify |  |  | Confirm connector, airflow direction and clearance
CTL-001 | Control | Arduino Uno R3 | 1 | Required | Arduino Uno R3 | USB serial; 5 V logic | Flash watchdog firmware; isolate motor noise; common ground at planned star point | Concept hardware | Verify |  |  | Bench-test serial protocol and E-stop sense
DRV-001 | Drive | L298N dual H-bridge module | 1 | Required | L298N red module | Motor rail; 5 V logic; PWM | Verify motor stall current and voltage drop stay within module thermal limits | Concept hardware | Blocker |  |  | Measure stall current; replace if margin is inadequate
DRV-002 | Drive | Geared DC motor | 4 | Required | Four motor/gearbox instances in CAD; exact model TBD | Paired left/right driver outputs | Matched set; rate each side channel for two motors and loaded stall current | CAD asset | TBD |  |  | Record model, ratio, no-load and individual/paired stall current
DRV-003 | Drive | Drive wheel | 4 | Required | Four wheel instances in CAD; nominal radius 33.622 mm | Mechanical | Measure loaded rolling radius; secure every hub without slip | CAD asset | Verify |  |  | Enter loaded radius in ROS and firmware configs
DRV-004 | Drive | Protected MOSFET dual-channel driver upgrade | 1 | Conditional | Exact part TBD after paired-motor current test | Motor rail; logic; PWM | Prefer a protected driver with margin above each side pair's measured stall current | Recommended upgrade | TBD |  |  | Replace L298N if voltage-drop, current or thermal margin is inadequate
ODO-001 | Odometry | Wheel quadrature encoder | 2 | Required | Optical or Hall encoder; exact part TBD | 5 V encoder to Arduino pins 2/4 and 3/12 | Use non-contact quadrature sensing rated for wheel RPM | Required upgrade | Blocker |  |  | Select encoder and measure effective counts/revolution
ODO-002 | Odometry | KY-040 rotary encoder module | 2 | Optional | KY-040 appears in source BOM/CAD | 5 V digital | Mechanical contact encoder is unsuitable for dependable high-speed wheel odometry | Replace | Replace |  |  | Keep only for low-speed UI/prototype input
SNS-001 | Perception | 2D LiDAR | 1 | Required | Customized hardware; protocol/model TBD | USB or UART to Jetson | ROS driver must publish sensor_msgs/LaserScan with valid timing | Concept hardware | Blocker |  |  | Document electrical interface, scan rate and ROS driver
SNS-002 | Perception | IMX219 wide-angle camera | 1 | Optional | IMX219 CSI camera | Jetson CSI | Confirm ribbon orientation, field of view, focus and driver support | CAD asset | Verify |  |  | Capture calibration images and create camera_info YAML
SNS-003 | Localization | MPU-6050 IMU | 1 | Required | MPU-6050 breakout | Arduino I2C A4/A5 | Rigid mount; calibrate bias/scale; no magnetometer heading | Concept hardware | Verify |  |  | Run stationary bias and axis-orientation calibration
SNS-004 | Localization | u-blox NEO-6M GNSS | 1 | Optional | NEO-6M with antenna | Jetson USB/UART | Outdoor use; 3.3 V UART levels; GNSS does not replace local odometry | Concept hardware | Verify |  |  | Confirm voltage/logic levels and outdoor fix quality
SNS-005 | Safety sensing | HC-SR04 ultrasonic module | 1 | Optional | HC-SR04 | Arduino pins 11/A0; 5 V | Front proximity aid only; not a safety-rated protective device | Concept hardware | Verify |  |  | Measure blind zone, cone and mounting crosstalk
PWR-001 | Power | Matched 18650 cells | 4 | Required | 2S2P implied by CAD holder; cell model TBD | 2S pack | Use identical genuine protected-grade cells from one batch; never mix condition/capacity | Concept/CAD | Blocker |  |  | Have pack assembled/inspected by a qualified person
PWR-002 | Power | 2S battery management system | 1 | Required | Current/chemistry rating TBD | Inside battery pack | Over-charge, over-discharge, over-current and balancing appropriate to cells | Required safety add | Blocker |  |  | Select from measured peak/stall current and cell datasheet
PWR-003 | Power | Main fuse and holder | 1 | Required | Rating TBD after fault-current analysis | Pack positive, close to cells | DC-rated interrupt capacity and cable protection | Required safety add | Blocker |  |  | Calculate wire ampacity and select fuse below weakest link
PWR-004 | Power | Physical dual-contact E-stop | 1 | Required | Latching twist-release; current rating TBD | Motor power contact + NC monitor contact | One contact removes motor energy; one NC auxiliary loop reports open/fault | Required safety add | Blocker |  |  | Perform continuity, broken-wire and power-removal tests
PWR-005 | Power | Main power switch | 1 | Required | Keyed/guarded switch recommended | Battery distribution | DC load rating above measured continuous current | Add | TBD |  |  | Select after power-budget measurement
PWR-006 | Power | 5 V regulated compute supply | 1 | Required | LM2596 appears in concept; higher-current regulator may be needed | 2S pack to Jetson 5 V rail | Low ripple; transient headroom; short-circuit/thermal protection | Concept hardware | Blocker |  |  | Load-test at Jetson peak current and verify connector polarity
PWR-007 | Power | Battery voltage divider | 1 | Required | 100 kΩ / 47 kΩ firmware default; verify | Pack sense to Arduino A2 | ADC must never exceed reference; calibrate against a trusted meter | Firmware default | Verify |  |  | Measure resistors and fit scale factor at two voltages
NET-001 | Connectivity | USB A-to-B data cable | 1 | Required | Shielded cable | Jetson to Arduino | Data-capable, strain-relieved and separated from motor leads | Add | TBD |  |  | Fit ferrite only if testing shows it is needed
NET-002 | Connectivity | GNSS USB-UART adapter | 1 | Optional | 3.3 V logic adapter if module lacks USB | Jetson USB to NEO-6M | Do not expose Jetson UART to 5 V logic | Conditional | TBD |  |  | Confirm module carrier interface before purchase
MEC-001 | Mechanical | Base, top and bottom covers | 1 | Required | SolidWorks source under 3D_Mechanical_Design | Mechanical | Check sharp edges, service access, ventilation and cable paths | CAD asset | Verify |  |  | Export manufacturing drawings and record material/finish
MEC-002 | Mechanical | Motor mount | 2 | Required | Motor_mount.step / SLDPRT | Mechanical | No flex or shaft misalignment at peak wheel load | CAD asset | Verify |  |  | Print/machine, torque fasteners and inspect alignment
MEC-003 | Mechanical | LiDAR plate | 1 | Required | LiDAR Plate.SLDPRT | Mechanical | Level, rigid and unobstructed scan plane | CAD asset | Verify |  |  | Measure transform from base_link and update URDF
MEC-004 | Mechanical | Camera holder | 1 | Optional | Camera Holder.SLDPRT | Mechanical | Rigid with repeatable pitch and clear field of view | CAD asset | Verify |  |  | Measure optical transform and calibrate intrinsics
MEC-005 | Mechanical | Ultrasonic holder | 1 | Optional | Ultrasound Holder.SLDPRT | Mechanical | No chassis reflections inside sensor cone | CAD asset | Verify |  |  | Range-test after final assembly
MEC-006 | Mechanical | Fasteners, spacers and locking hardware | 1 | Required | M3 hardware appears in CAD; schedule TBD | Mechanical | Use correct length, thread engagement and vibration retention | Partial CAD | TBD |  |  | Create drawing-derived fastener schedule
WIR-001 | Wiring | Color-coded stranded wire and terminals | 1 | Required | Gauge and connector family TBD | Power and signal harnesses | Size from measured current; crimp with correct tooling; label both ends | Add | Blocker |  |  | Create harness drawing and pull-test sample crimps
WIR-002 | Wiring | Motor noise suppression | 2 | Required | Capacitors/ferrites as validated | At motor terminals/harness | Select from scope testing; keep motor loops short and twisted | Add | TBD |  |  | Check resets/serial CRC errors under acceleration
WIR-003 | Wiring | Distribution board or fused terminal block | 1 | Required | Exact implementation TBD | Battery, motor and logic rails | Star return plan; strain relief; no exposed energized conductors | Missing from concept | Blocker |  |  | Create schematic and peer-review before power-up
LAB-001 | Commissioning | Current-limited bench supply | 1 | Tool | Appropriate voltage/current range | Lab equipment | Use for first power and motor polarity tests | Tool | Verify |  |  | Record current limits in commissioning log
LAB-002 | Commissioning | Digital multimeter | 1 | Tool | CAT/rating appropriate to work | Lab equipment | Verify polarity, rails, continuity and divider calibration | Tool | Verify |  |  | Check calibration status
Source basis: the original repository README and filenames in 3D_Mechanical_Design/P&G Wildebeest_Pro. Added items are engineering controls or missing integration parts; exact vendor selections remain owner inputs. | Source basis: the original repository README and filenames in 3D_Mechanical_Design/P&G Wildebeest_Pro. Added items are engineering controls or missing integration parts; exact vendor selections remain owner inputs. | Source basis: the original repository README and filenames in 3D_Mechanical_Design/P&G Wildebeest_Pro. Added items are engineering controls or missing integration parts; exact vendor selections remain owner inputs. | Source basis: the original repository README and filenames in 3D_Mechanical_Design/P&G Wildebeest_Pro. Added items are engineering controls or missing integration parts; exact vendor selections remain owner inputs. | Source basis: the original repository README and filenames in 3D_Mechanical_Design/P&G Wildebeest_Pro. Added items are engineering controls or missing integration parts; exact vendor selections remain owner inputs. | Source basis: the original repository README and filenames in 3D_Mechanical_Design/P&G Wildebeest_Pro. Added items are engineering controls or missing integration parts; exact vendor selections remain owner inputs. | Source basis: the original repository README and filenames in 3D_Mechanical_Design/P&G Wildebeest_Pro. Added items are engineering controls or missing integration parts; exact vendor selections remain owner inputs. | Source basis: the original repository README and filenames in 3D_Mechanical_Design/P&G Wildebeest_Pro. Added items are engineering controls or missing integration parts; exact vendor selections remain owner inputs. | Source basis: the original repository README and filenames in 3D_Mechanical_Design/P&G Wildebeest_Pro. Added items are engineering controls or missing integration parts; exact vendor selections remain owner inputs. | Source basis: the original repository README and filenames in 3D_Mechanical_Design/P&G Wildebeest_Pro. Added items are engineering controls or missing integration parts; exact vendor selections remain owner inputs. | Source basis: the original repository README and filenames in 3D_Mechanical_Design/P&G Wildebeest_Pro. Added items are engineering controls or missing integration parts; exact vendor selections remain owner inputs. | Source basis: the original repository README and filenames in 3D_Mechanical_Design/P&G Wildebeest_Pro. Added items are engineering controls or missing integration parts; exact vendor selections remain owner inputs. | Source basis: the original repository README and filenames in 3D_Mechanical_Design/P&G Wildebeest_Pro. Added items are engineering controls or missing integration parts; exact vendor selections remain owner inputs.

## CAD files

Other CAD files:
3D_Mechanical_Design/P&G Wildebeest_Pro/Cable_11-Wildebeest_Nano.SLDASM
3D_Mechanical_Design/P&G Wildebeest_Pro/IMX219 with Wide Angle Lens.SLDASM
3D_Mechanical_Design/P&G Wildebeest_Pro/Harness_13-Wildebeest_Nano.SLDASM
3D_Mechanical_Design/P&G Wildebeest_Pro/Ribbon cable_13-Wildebeest_Nano.SLDASM
3D_Mechanical_Design/P&G Wildebeest_Pro/Harness_19-Wildebeest_Nano.SLDASM
3D_Mechanical_Design/P&G Wildebeest_Pro/KY-040 Rotary Encoder.SLDASM
3D_Mechanical_Design/P&G Wildebeest_Pro/A_GPS_ant.SLDASM
3D_Mechanical_Design/P&G Wildebeest_Pro/Harness_5-Wildebeest_Nano.SLDASM
3D_Mechanical_Design/P&G Wildebeest_Pro/Cable_3-Autonomous_robot_v1.SLDASM
3D_Mechanical_Design/P&G Wildebeest_Pro/MPU 6050 IMU.SLDASM
3D_Mechanical_Design/P&G Wildebeest_Pro/bouton (installé).SLDASM
3D_Mechanical_Design/P&G Wildebeest_Pro/Harness_15-Wildebeest_Nano.SLDASM
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

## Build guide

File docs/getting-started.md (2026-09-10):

# Readiness and compatibility

Use this page to select a supported deployment and decide whether the robot is ready to assemble. Do not start by installing packages on an unknown Jetson image or connecting a battery to an unverified harness.

## 1. Identify the exact platform

On the Jetson, capture the following before changing the OS:

```bash
cat /etc/os-release
uname -a
test -r /etc/nv_tegra_release && cat /etc/nv_tegra_release
python3 --version
```

Photograph the module and carrier-board labels, then record the RAM variant, carrier revision, storage medium, power-input method, and JetPack/L4T release in the [configuration record](reference/configuration-record.md). Jetson Nano developer kits belong to NVIDIA's JetPack 4 generation; do not assume instructions for newer Orin hardware or JetPack 5/6 apply.

## 2. Select a software profile

| Profile | Host OS | ROS | Use when | Important constraint |
|---|---|---|---|---|
| **ROS 2 workstation / split-compute (reference)** | Ubuntu 24.04 on a supported workstation; Nano retains its validated vendor image | Jazzy | Developing and validating the maintained ROS 2 stack while preserving Nano CSI/GPU support | Hardware transport across the split is integration work; never expose unauthenticated DDS to an untrusted network |
| **ROS 2 native on replacement compute** | Ubuntu 24.04 arm64 on a capable supported SBC | Jazzy | A single-computer ROS 2 robot is more important than retaining Nano-specific hardware | Revalidate power, camera, GPIO/device interfaces, thermals, mounts and performance as a hardware revision |
| **ROS 2 experimental native Nano** | Custom image/build | Jazzy-compatible source environment | A maintainer deliberately owns kernel, camera, GPU and ROS source compatibility | Not a supported baseline; attach complete build and hardware evidence |
| **ROS 1 legacy** | Ubuntu 20.04 | Noetic | Reproducing an existing ROS 1 integration | Noetic is end-of-life; isolate it and plan migration |
| **Simulation/development** | Ubuntu 24.04 workstation | Jazzy | Developing without hardware | Simulation does not validate current draw, wiring, timing, traction, or sensor noise |

!!! warning "Do not force an OS/ROS mismatch"
    ROS 2 Jazzy targets Ubuntu 24.04 on 64-bit ARM and x86-64. ROS 1 Noetic's binary target is Ubuntu 20.04 and it is now end-of-life. A stock Jetson Nano JetPack 4 image uses a legacy Ubuntu base to retain its vendor kernel, CSI camera, and GPU stack; it cannot natively use the repository's supported Jazzy/24.04 profile. Building ROS from source, using containers, or replacing the Jetson image are separate engineering projects with camera, CUDA, kernel, GPIO, and maintenance tradeoffs—not interchangeable install commands.

The official [ROS 2 Jazzy Ubuntu installation page](https://docs.ros.org/en/jazzy/Installation/Ubuntu-Install-Debs.html), [ROS 1 end-of-life notice](https://www.ros.org/blog/noetic-eol/), and [NVIDIA JetPack 4.6 archive](https://developer.nvidia.com/embedded/jetpack-sdk-46) provide the upstream constraints. The [ROS 1 bridge compatibility table](https://docs.ros.org/en/humble/p/ros1_bridge/index.html) also explains why bridging modern Ubuntu releases is not a universal migration solution.

## 3. Inventory before purchase or assembly

Confirm all of these with the actual product label and datasheet:

- [ ] Jetson module/carrier revision and supported power-input path
- [ ] Arduino Uno board type and USB interface
- [ ] L298N module schematic, jumper behavior, logic supply arrangement, and terminal labels
- [ ] Motor nominal/stall current, nominal voltage, gearbox ratio, and encoder electrical interface
- [ ] Encoder counts per motor/output-shaft revolution and decoding convention
- [ ] Exact 2D LiDAR model, interface, supply, ROS driver, and scan direction
- [ ] IMX219 module compatibility with the carrier and ribbon orientation
- [ ] MPU6050 breakout input voltage, I²C pull-up voltage, and address
- [ ] NEO-6M breakout input voltage, UART logic level, antenna, and update rate
- [ ] Number and placement of HC-SR04 modules
- [ ] Battery cell provenance, configuration, capacity, protection/BMS, approved charger, connector, fuse, and enclosure
- [ ] Buck regulator input/output range and **continuous** current with thermal margin
- [ ] Latching emergency stop or equivalent motor-power disconnect
- [ ] Wire gauge, connector current rating, strain relief, insulation, and polarity keying

Unknown items stay `TBD`; they are not permission to use a convenient value.

## 4. Host prerequisites

For the selected Ubuntu/ROS combination:

1. Install the ROS distribution using its official instructions.
2. Ensure `git`, the appropriate build tool (`colcon` for ROS 2 or Catkin tools for ROS 1), `rosdep`, and Python 3 are present.
3. Clone this repository without `sudo`.
4. Run the repository bootstrap script only after reviewing it:

    ```bash
    ./scripts/bootstrap.sh ros2   # or ros1
    ./scripts/build.sh ros2       # or ros1
    ```

5. Use a normal user account. Add only the minimum serial-device access needed by your distribution; log out and back in after group changes.
6. Pin the working OS image and dependencies in the configuration record. Keep a restorable storage image once camera, LiDAR, and serial access have been proven.

The bootstrap script prepares repository dependencies; it cannot choose the correct JetPack image, battery protection, LiDAR driver, or camera ribbon orientation for you.

## 5. Readiness gates

| Gate | Pass condition |
|---|---|
| Documentation | All safety-critical TBDs in the configuration record have an owner and evidence |
| Mechanical | Wheels rotate freely; fasteners are retained; wiring cannot contact wheels, gears, fan, or sharp edges |
| Electrical | Unpowered continuity/polarity checks pass; each regulated rail is set and tested with the load disconnected |
| Firmware | Arduino boots with motor outputs disabled; emergency-stop and 300 ms watchdog behavior are bench-proven |
| ROS | Workspace builds; launch has no duplicate TF/topic owners; diagnostics expose every required device |
| Simulation | Command arbitration, odometry, TF, and stop paths pass before real motor power is enabled |
| Physical test | Staged acceptance through lifted-wheel testing is signed off before floor motion |

If any gate fails, stop at that layer. For example, a clean RViz display cannot waive a failed polarity check.

## 6. First-day success criterion

The goal is not autonomous navigation. A successful first session ends with:

- the exact hardware documented;
- software built in simulation;
- the Arduino reporting healthy telemetry with motor power physically disconnected;
- the emergency stop verified by continuity test; and
- a captured test record.

Proceed to [wiring and pinout](hardware/wiring.md) only after that baseline exists.

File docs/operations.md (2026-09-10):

# Operations runbook

This runbook governs supervised prototype operation. Tailor it only through a reviewed configuration record and risk assessment. Autonomous operation around uninvolved people, public roads, drop-offs, traffic, animals, stairs, water, flammable material, or an uncontrolled radio network is outside the baseline scope.

## Roles and test area

For first motion and autonomous tests, use at least:

- **operator** — controls software and commands;
- **safety observer** — watches the robot and owns immediate access to the hard E-stop; not occupied with a laptop;
- **test lead** — may be one of the above only after the procedure is mature; authorizes stage and records result.

Mark a controlled exclusion zone, remove trip hazards, block stairs/drop-offs physically, provide a clear run-off area, and keep bystanders outside. Establish the spoken stop word and who may reset the E-stop.

## Operating states

```mermaid
stateDiagram-v2
    [*] --> Isolated: main disconnect open
    Isolated --> PoweredSafe: logic on / motor E-stop asserted
    PoweredSafe --> Ready: diagnostics pass / zero command
    Ready --> Manual: E-stop released / teleop selected
    Manual --> Autonomous: stage authorized / navigation selected
    Autonomous --> Manual: autonomy cancelled
    Ready --> Stopped: software or hard stop
    Manual --> Stopped: timeout, fault, or stop
    Autonomous --> Stopped: timeout, fault, or stop
    Stopped --> PoweredSafe: cause understood / hard stop asserted
    PoweredSafe --> Isolated: orderly compute shutdown / disconnect open
```

There is no transition directly from fault to motion. Diagnose, document, return to a safe state, and repeat the affected checklist.

## Before every run

### Physical

- [ ] Authorized test stage, area, surface, slope, payload and weather confirmed
- [ ] Chassis, all four wheels/motors, sensors, battery and fastener retention inspected
- [ ] No pinched, abraded, loose or hot/discolored wiring; terminals guarded
- [ ] Cooling path clear; fan rotates freely; sensor apertures clean
- [ ] Battery undamaged, within approved state/temperature envelope, secured and disconnected from charger
- [ ] Main fuse correct and intact; no bypass wire or oversize substitute
- [ ] Main disconnect and hard E-stop operate mechanically
- [ ] E-stop main contact interrupts motor branch; auxiliary loop reports released `LOW`, pressed/open-wire `HIGH`
- [ ] Safety observer positioned with direct E-stop access

### Software/configuration

- [ ] Robot ID, commit, firmware build and parameter set match the approved record
- [ ] Correct ROS domain/master and time source; no unknown graph participants
- [ ] Real versus mock/simulation mode explicitly confirmed
- [ ] Unique `/cmd_vel`, `map -> odom`, and `odom -> base_link` ownership
- [ ] Calibrated geometry, limits, footprint and sensor transforms loaded
- [ ] Sufficient disk space for logs; privacy scope agreed
- [ ] All required diagnostics healthy or an approved degraded-mode procedure applies

## Startup

1. Press/latch the hard E-stop and keep command input neutral.
2. Open the main motor path. Connect the approved battery only if the harness inspection passes.
3. Energize the logic/compute path according to the released power sequence.
4. Wait for the Jetson/sensor computer to boot; confirm no motor energy is present.
5. Check system identity, storage, clock, temperature and devices:

    ```bash
    date --iso-8601=seconds
    df -h
    ls -l /dev/serial/by-id/
    python3 tools/robot_doctor.py
    ```

6. Start the selected ROS environment.

    === "ROS 2"

        ```bash
        source /opt/ros/jazzy/setup.bash
        source ros2_ws/install/setup.bash
        ros2 launch wildebeest_bringup robot.launch.py \
          use_sim:=false transport:=serial serial_port:=/dev/wildebeest-base
        ```

    === "ROS 1"

        ```bash
        source /opt/ros/noetic/setup.bash
        source ros1_ws/devel/setup.bash
        roslaunch wildebeest_bringup robot.launch \
          use_sim:=false base_port:=/dev/wildebeest-base sensors:=false joystick:=false
        ```

7. Confirm firmware boot/protocol, watchdog-stopped state, fresh odometry/required sensors, TF ownership and diagnostics.
8. Start logging. State aloud that the motor branch is about to be enabled.
9. Energize the motor branch while the hard E-stop remains pressed; verify the driver output is inactive.
10. With command still zero and observer ready, release the hard E-stop. Confirm the A1 status becomes healthy and no wheel moves.
11. Clear the software stop deliberately if engaged. Reconfirm zero command.
12. Enter the authorized test mode at the lowest validated limits.

Any unexpected movement returns immediately to hard-stop and isolated states.

## Manual motion checkout

Before autonomy, perform brief supervised commands:

1. zero command and command-source timeout;
2. forward and reverse;
3. counter-clockwise and clockwise rotation;
4. left/right arcs;
5. release of the teleop control (dead-man behavior where provided);
6. software stop;
7. hard stop at low speed;
8. recovery requiring deliberate clear and fresh command.

Compare wheel signs, odometry, TF, IMU yaw rate and visible motion. Abort on disagreement.

## Mapping

Use teleoperation and reduced limits. Start with a clean, static indoor environment and known loop closures.

```bash
# ROS 2
ros2 launch wildebeest_navigation navigation.launch.py slam:=true

# ROS 1
roslaunch wildebeest_navigation mapping.launch
```

Drive slowly with overlap and avoid moving objects where practical. Save the map with a unique environment/date/revision, inspect occupancy and scale, and record its origin. A blank/example map shipped with the repository is never an operational map.

## Localized navigation

Before setting a goal:

- load the reviewed map;
- set/verify the initial pose;
- compare LiDAR returns to mapped walls;
- check covariance converges plausibly;
- verify footprint and costmaps around the stationary robot;
- confirm recovery behaviors cannot cross physical hazards;
- confirm command source priority and stop path.

Start with one short goal inside the exclusion zone. The observer tracks the robot, not RViz. Pause after every anomaly instead of repeatedly commanding recovery.

## Outdoor/GNSS extension

Outdoor operation is not enabled merely by receiving `/gps/fix`. Require:

- declared outdoor environmental envelope and physical containment;
- valid datum/local projection policy;
- verified heading source and low-speed behavior;
- GNSS quality/covariance gates and multipath tests;
- local obstacle sensing independent of GNSS;
- loss-of-fix behavior and geofence validated without relying solely on software;
- legal/site authorization.

The NEO-6M is not a safety-rated geofence or collision-avoidance sensor.

## Logging

At minimum capture commands before/after arbitration, odometry, joint states, TF, diagnostics and sensors relevant to the test. Log configuration/commit/firmware identity alongside the bag.

Camera and GNSS can contain faces, license plates, interiors and precise location. Minimize collection, restrict access, define retention, and remove sensitive data before sharing. Never record secrets.

Monitor disk usage and write rate. A full disk or overloaded storage can destabilize the robot; logging must not be allowed to starve control.

## Normal shutdown

1. Cancel navigation/teleop and publish/confirm zero command.
2. Engage software stop.
3. Press the hard E-stop and verify motor power is removed.
4. Stop recording and save the run metadata/result.
5. Stop ROS processes; verify no background driver remains.
6. Shut down the Jetson/compute OS cleanly and wait for its documented power-off indication.
7. Open the main service disconnect and disconnect the battery if the design calls for it.
8. Inspect for heat, odor, loose parts, damage and abnormal battery condition.
9. Quarantine/label faults and update the maintenance log.

Do not remove Jetson power while storage is being written except when needed to prevent a greater hazard.

## Emergency response

### Unexpected motion or loss of control

1. Press the hard E-stop—do not troubleshoot through the terminal first.
2. Keep people clear until wheels and mechanisms stop.
3. Open the service disconnect when safe.
4. Preserve logs and scene; label the robot out of service.
5. Identify the failed safety layers and repeat fault-injection tests before release.

### Smoke, swelling, hissing, electrolyte odor or excessive battery heat

Do not touch, move, charge, or reconnect the pack. Clear people, contact site emergency personnel, and follow the battery/charger manufacturer's and facility's lithium-ion incident procedure. The correct response and extinguishing equipment depend on the pack and site; define them before operation.

### Collision or tip-over

Hard-stop and isolate energy. Inspect battery, chassis, shafts, mounts, sensor extrinsics, wiring and connectors. Re-run calibration/acceptance affected by the impact even if the robot appears intact.

## Maintenance triggers

Inspect before every run and after transport/impact. Repeat the appropriate tests after:

- firmware, ROS, parameter, OS, driver or network changes;
- wheel, motor, encoder, driver, battery, regulator, fuse or connector changes;
- camera focus/mode or sensor mount movement;
- harness repair or intermittent communication;
- overheating, brownout, watchdog, CRC or estimator anomalies;
- long storage or battery service.

Set time/cycle-based intervals only after component manuals and wear data are available; record them in the robot configuration rather than inventing universal hours here.

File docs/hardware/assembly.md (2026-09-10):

# Mechanical assembly

The repository contains an original SolidWorks assembly and component models. Treat them as a starting point for fit and packaging. Material specifications, tolerances, fastener torque, final mass properties, wiring clearances, and drawing release status are not established by the files alone.

## Assembly sequence

### 1. Review and measure

- Open the top-level assembly and confirm document units.
- Create dimensioned manufacturing drawings for every custom part.
- Compare hole patterns and connector locations with the physical Jetson carrier, Arduino, driver, regulators, sensors, motors, and battery.
- Check the assembled wheel radius, track, and wheelbase against the CAD-derived URDF baselines, but do not edit measurements to make the CAD agree.
- Weigh major components and estimate center of gravity in the fully wired configuration.
- Define service access for fuse, disconnect, E-stop, storage, USB, charge connector, and fasteners.

Record every mismatch as either a CAD change, approved adapter, or rejected part.

### 2. Dry-build the rolling chassis

Assemble without electronics or battery:

1. Install motor mounts loosely, align shafts, then secure using the selected retention method.
2. Install wheels and verify axial/radial clearance through a full rotation.
3. Fit all four wheel and motor assemblies so every tire remains loaded on a level surface and neither diagonal pair rocks.
4. Confirm the frame is not twisted and wheel axes are parallel.
5. Check ground clearance and approach paths at the intended payload.
6. Push the chassis by hand; investigate binding, gear noise, wobble, or asymmetry.

### 3. Fit sensor mounts

| Sensor | Placement rule | Verification |
|---|---|---|
| LiDAR | Scan plane unobstructed; rigid, level, protected without blocking the aperture | Full 360° visualization against known walls; no chassis returns in usable sector unless masked/documented |
| Camera | Rigid mount, lens unobstructed, ribbon within bend limits | Focus, exposure, resolution, optical-frame orientation |
| GNSS antenna | Clear sky view, separated from switching noise and high-current wiring | Cold/warm acquisition and fix stability outdoors |
| IMU | Rigid near chassis body, away from heat/vibration/fields; axes measurable | Stationary bias and known-axis rotation checks |
| Ultrasonic | Faces intended hazard region; no cover lip in beam | Known targets across operating range and angles |
| Encoders | Concentric/secure with no contact or missed motion | Counts are repeatable in both directions |

Measure sensor origins and orientation relative to `base_link`; nominal mount geometry is only an initial estimate for URDF.

### 4. Fit electrical hardware

- Use insulating standoffs; prevent solder joints or terminal screws touching structure.
- Keep exposed power terminals guarded and inaccessible to loose hardware.
- Put the fuse close to the battery branch source and make it serviceable.
- Locate the main disconnect and E-stop where a nearby observer can reach them without entering the robot's path.
- Mount the battery against movement in every axis without crushing or puncturing it.
- Preserve Jetson/fan and regulator airflow; avoid recirculating hot motor-driver air.
- Separate high-current/PWM wiring from encoder, I²C, UART, CSI, and GNSS antenna paths.
- Provide drip loops and environmental protection appropriate to the declared indoor/outdoor scope. The baseline robot is not weatherproof.

### 5. Build and label the harness

Build the harness from the reviewed [wiring and pinout](wiring.md), with the battery absent. Use a consistent labeling scheme at both ends, for example `MTR-L+`, `ENC-R-B`, `5V-SENS`, and `GND-LOGIC`. Crimp with the tool specified for the terminal; pull-test sample crimps. Do not tin stranded wire before screw terminals unless the terminal manufacturer explicitly permits it.

Protect cables from:

- wheel/gear/pinch-point ingress;
- sharp sheet edges and fastener threads;
- repeated flex at connectors;
- hot driver/regulator surfaces;
- antenna or sensor field-of-view obstruction.

### 6. Perform unpowered inspection

- [ ] No battery installed; fuse removed; all switches open
- [ ] Fasteners present and retained; no loose metal inside enclosure
- [ ] All four wheels rotate freely; each same-side pair has matched direction and no binding
- [ ] Board standoffs insulating and structurally secure
- [ ] Polarized connectors match the wiring record
- [ ] Continuity from each source to intended load only
- [ ] No unexpected continuity from any rail to chassis or another rail
- [ ] Emergency stop opens the motor branch and its status contact changes independently
- [ ] Camera ribbon orientation checked at both ends
- [ ] Harness clear of fan, wheels, gearbox, sharp edges, and sensor apertures

Two people should independently inspect battery polarity and motor-branch interruption before first power.

## First-power sequence

1. Place the chassis on a stable stand with wheels clear; keep the battery disconnected.
2. Remove motor outputs or motor-branch fuse.
3. Power one regulator/input path from a current-limited bench supply.
4. Confirm current and all destination voltages; shut down and inspect temperature.
5. Add one load at a time: Arduino, Jetson, then sensors.
6. Verify Arduino boot produces no enable/PWM motion state.
7. Verify serial telemetry and diagnostics with the L298N motor rail still absent.
8. Power the L298N logic only as its module design permits; verify outputs remain safe.
9. Connect one motor at a time and energize the motor branch at the lowest practical current limit.
10. Prove E-stop interruption, watchdog timeout, direction, and encoder sign for every motor before connecting the two same-side pairs.

If a current limit trips, diagnose the cause. Raising the limit is not a diagnostic step.

## Mechanical release checklist

A chassis is released for low-speed floor testing only when:

- as-built photos and measured dimensions exist;
- mass and center-of-gravity behavior are acceptable on the declared slope/acceleration envelope;
- motor, wheel, and battery retention have witness marks or an equivalent inspection method;
- wires remain clear during full wheel rotation and handling;
- all sensor frames have measured transforms;
- guards/enclosure prevent accidental contact with energized terminals and pinch points;
- cooling passes the stationary worst-case thermal test;
- emergency stop is visible, labeled, reachable, and proven under motor load.

Re-run relevant checks after any impact, transport, wheel/motor change, battery change, harness repair, or sensor-mount adjustment.

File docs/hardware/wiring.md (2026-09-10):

# Wiring and pinout

This chapter defines the reference harness for the repository firmware. It is not evidence that the original CAD wiring is correct. Module variants differ; verify labels against schematics and measurements at the connector in hand.

!!! danger "Verify before every first power-up"
    Disconnect the battery and USB. Remove the motor-supply fuse. Check every conductor end-to-end, verify there are no shorts between power and ground, set each regulator with its load disconnected, and confirm polarity at the destination connector. First energize each rail from a current-limited bench supply. Stop immediately on unexpected current, heat, odor, sound, or voltage.

## Reference power topology

```mermaid
flowchart LR
    B[Protected 2S pack] --> D[Main service disconnect]
    D --> F1[Motor branch fuse]
    F1 --> E[Latched hard E-stop]
    E --> VM[L298N motor supply]
    VM --> ML[Left front + rear motor pair]
    VM --> MR[Right front + rear motor pair]

    D --> F2[Compute branch protection]
    F2 --> R1[Verified regulator / input path]
    R1 --> J[Jetson Nano]

    J -->|USB data + logic power as designed| A[Arduino Uno]
    J --> L[2D LiDAR]
    J --> G[GNSS adapter]
    J --> C[IMX219 CSI]
    A --> I[MPU6050]
    A --> U[HC-SR04]

    B -. voltage divider only .-> ADC[Arduino A2]
```

Use a two-contact, mechanically linked E-stop arrangement:

1. A suitably rated normally-closed main contact is in series with the motor-power path. Healthy/released is closed; pressing the E-stop opens the contact and removes L298N motor energy.
2. A separate, isolated normally-closed auxiliary contact connects Arduino A1 to Arduino ground. Healthy/released reads `LOW`; pressing, unplugging, or breaking the sense wire opens the loop, the Uno's `INPUT_PULLUP` makes A1 `HIGH`, and firmware reports hard E-stop asserted.

The auxiliary circuit reports status only. **Never route motor current into A1, Arduino ground traces, or through an Arduino board.** Verify the selected E-stop's DC contact ratings, positive-opening behavior where required, contact isolation, and mechanical linkage from its actual datasheet.

The exact Jetson power path depends on its carrier revision. Use only the carrier manufacturer's documented input and settings. Do not back-power the Jetson through a GPIO header, CSI connector, Arduino USB path, or sensor pin.

## Arduino reference pin map

These are the repository firmware defaults and can be overridden in `Config.h`. Any override must be changed in the wiring record, firmware build metadata, and acceptance evidence together.

| Arduino pin | Firmware signal | Connects to | Direction at Arduino | Commissioning note |
|---|---|---|---|---|
| D2 | Left encoder A | Left encoder channel A | input | Interrupt-capable on Uno; verify pull-up/output type |
| D4 | Left encoder B | Left encoder channel B | input | Verify A/B phase and sign |
| D3 | Right encoder A | Right encoder channel A | input | Interrupt-capable on Uno; verify max edge rate |
| D12 | Right encoder B | Right encoder channel B | input | Verify A/B phase and sign |
| D5 | L298N ENA | Left-pair channel enable/PWM | output | PWM; remove/handle board enable jumper as its schematic requires |
| D7 | L298N IN1 | Left-channel direction input 1 | output | Motor polarity is calibrated with wheels lifted |
| D8 | L298N IN2 | Left-channel direction input 2 | output | Must boot to disabled/zero state |
| D6 | L298N ENB | Right-pair channel enable/PWM | output | PWM; remove/handle board enable jumper as its schematic requires |
| D9 | L298N IN3 | Right-channel direction input 1 | output | Motor polarity is calibrated with wheels lifted |
| D10 | L298N IN4 | Right-channel direction input 2 | output | Must boot to disabled/zero state |
| D11 | Ultrasonic trigger | Front HC-SR04 TRIG | output | Trigger schedule must prevent crosstalk |
| A0 | Ultrasonic echo | Front HC-SR04 ECHO | input | Reference connection is to 5 V Uno, **not** Jetson GPIO |
| A1 | Hard E-stop sense | NC auxiliary contact to Arduino GND | input with internal pull-up; `LOW` healthy, `HIGH` asserted/open-wire | Status only; main NC contact separately interrupts motor energy |
| A2 | Battery sense | Engineered resistor divider/filter | analog input | Never connect pack voltage directly; verify worst-case pin voltage |
| A4 | I²C SDA | MPU6050 SDA | bidirectional | Verify breakout pull-up voltage |
| A5 | I²C SCL | MPU6050 SCL | output/bidirectional | Verify address and bus integrity |
| USB serial | Base link | Jetson USB | bidirectional | 115200 baud, 8-N-1 |

Pins D0/D1 remain unused by the reference harness so USB serial is not electrically contended.

## Jetson connection map

| Device | Preferred interface | Verify before connection |
|---|---|---|
| Arduino | USB | Cable is data-capable; stable `/dev/serial/by-id/...` path; USB power interaction documented |
| 2D LiDAR | Model-specific USB/serial | Exact supply source/current, logic level, USB identity, driver and permissions |
| NEO-6M | Verified USB-to-UART adapter or documented carrier UART | GNSS breakout supply and UART logic level; RX/TX crossed correctly; shared ground |
| IMX219 | CSI ribbon | Jetson powered off; connector unlocked/locked correctly; contact orientation and lane compatibility |

Jetson GPIO is 3.3 V logic and is not 5 V tolerant. No HC-SR04 echo, Arduino output, or unspecified breakout signal may be connected directly to it. Use a correctly designed level translator where a direct GPIO/UART/I²C connection is deliberately engineered.

## L298N terminal checklist

Labels and jumpers vary among L298N boards. Identify from the actual module schematic:

- motor-supply input and return;
- logic-supply input/output behavior;
- whether a regulator-enable jumper makes a pin an output rather than an input;
- ENA/ENB jumper behavior;
- OUT1/OUT2 and OUT3/OUT4 motor pairs;
- the board's thermal/current limits and any onboard protection.

!!! warning "Never tie power outputs together"
    Do not connect an L298N module's onboard-regulator output to a Jetson/Arduino 5 V rail or another regulator output unless the power architecture explicitly proves safe current sharing/backfeed behavior. Usually the correct action is to use one documented logic source and configure the module jumper accordingly.

The motor supply and logic ground need a defined common reference unless a deliberately isolated interface is used. Route high motor current directly back to the power distribution point, not through an Arduino, Jetson, USB shield, breadboard, or encoder ground wire.

The four-wheel chassis pairs its front and rear motors by side. Do not connect a
pair until individual polarity is matched and the channel, connector, wire,
fuse, and supply have margin above the pair's measured worst-case current. The
reference L298N is a commissioning blocker if that margin cannot be proved.

## Encoder and motor harness

For each side:

1. Identify motor terminals independently from encoder power and outputs.
2. Verify encoder supply and output voltage with the motor disconnected.
3. Determine whether outputs are push-pull, open-collector/open-drain, or mechanical contacts.
4. Select pull-ups and filtering appropriate to that output; do not assume Arduino internal pull-ups are sufficient.
5. Twist motor leads together. Route encoder power/signals separately from motor and PWM wiring.
6. Add strain relief at the motor, chassis transition, and controller.
7. With wheels lifted and motor supply current-limited, establish the direction/encoder sign matrix in [calibration](../calibration.md).

KY-040-style hand-rotary modules are often mechanically and electrically different from motor-shaft encoders. Confirm that the installed sensors can sustain the shaft speed and environment; the CAD label does not establish suitability.

## MPU6050 wiring

The reference path is Arduino I²C on A4/A5. Before connecting:

- identify breakout `VCC`, `GND`, `SDA`, `SCL`, address select, and any interrupt pin;
- determine whether the breakout contains a regulator and level shifters;
- measure the idle SDA/SCL high level;
- ensure no pull-up drives a device beyond its I/O limit;
- mount rigidly with axes documented relative to `base_link`.

Keep I²C short and away from motor leads. If errors appear only under motor load, investigate grounding, EMI, pull-ups, and physical routing rather than masking the issue with retries.

## HC-SR04 wiring

The reference front sensor uses D11 for trigger and A0 for echo on the 5 V Arduino. Record the actual module supply and characterize its valid range and beam. A timeout is a missing measurement, not a maximum-range obstacle-free result.

For multiple modules:

- allocate a unique echo input per sensor;
- trigger sequentially with enough quiet time for the environment;
- reject late echoes from the previous sensor;
- angle and separate modules to limit acoustic coupling;
- expose each as its own `sensor_msgs/Range` frame/topic;
- verify behavior against soft, angled, narrow, and cross-talking targets.

## Battery measurement input

Arduino A2 is reserved for a resistor divider/filter, but the divider values are intentionally unspecified. Design it from:

- the maximum credible pack voltage, including charger/fault cases;
- Arduino ADC absolute and recommended input limits;
- resistor tolerance and ADC source-impedance guidance;
- expected noise and filter settling;
- acceptable standby drain;
- calibration against a traceable meter.

Add an analysis showing that the worst tolerance stack remains within the pin limit. Firmware scaling without a safe physical divider does nothing to protect the input.

## Harness verification record

Complete and retain this table for every hardware revision:

| Check | Battery disconnected | Bench supply current limit | Battery power | Evidence |
|---|:---:|:---:|:---:|---|
| Pack connector polarity and keying | required | n/a | required | photo + meter reading |
| No power-to-ground short on each rail | required | required | required | resistance/current log |
| Regulator no-load output | required setup | required | optional | meter reading |
| Regulator loaded output and ripple | n/a | required | required | scope/log |
| E-stop removes motor rail | continuity | required | required | measurement/video |
| E-stop sense: released=`LOW`, pressed/open-wire=`HIGH` | continuity | required | required | logic reading |
| Motor current avoids logic harness | visual | required | required | annotated harness photo |
| Battery divider worst-case safe | analysis | required | required | calculation + ADC/meter log |
| USB/logic backfeed absent or controlled | continuity | required | required | power-state matrix |

Test the power-state matrix with Jetson off/on, USB unplugged/plugged, motor rail off/on, and charger disconnected/connected only where the pack manufacturer permits charging in-system. No state may energize a supposedly isolated rail through a signal cable.

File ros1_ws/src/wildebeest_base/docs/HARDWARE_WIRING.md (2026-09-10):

# Arduino Uno wiring reference

This mirrors the repository-root firmware source of truth in `firmware/wildebeest_base/include/Config.h` and the canonical design in `docs/hardware/wiring.md`. Check both files, the actual PCB, and every component datasheet before applying power; do not treat this installed package copy as authoritative.

| Function | Uno pin | Notes |
| --- | --- | --- |
| Left encoder A / B | D2 / D4 | A uses interrupt 0; inputs use pull-ups |
| Right encoder A / B | D3 / D12 | A uses interrupt 1; inputs use pull-ups |
| L298N ENA / IN1 / IN2 | D5 / D7 / D8 | D5 is PWM; remove ENA jumper |
| L298N ENB / IN3 / IN4 | D6 / D9 / D10 | D6 is PWM; remove ENB jumper |
| HC-SR04 trigger / echo | D11 / A0 | Echo is safe at Uno 5 V, never route it directly to Jetson GPIO |
| Normally closed hard-stop auxiliary loop | A1 | Healthy/released is `LOW`; pressed, unplugged, or broken wire opens the loop and reads `HIGH` through `INPUT_PULLUP` |
| Battery divider output | A2 | 100 kOhm / 47 kOhm default ratio is 3.1277; calibrate and keep A2 at or below 5 V |
| MPU6050 SDA / SCL | A4 / A5 | I2C address `0x68`; confirm module voltage/regulator design |
| Jetson link | USB serial | D0/D1 remain reserved for the USB UART |

The chassis has four driven wheels, but protocol v1 and this Uno pin budget expose one motor command and one effective encoder count per side. Both left motors and both right motors therefore behave as coupled skid-steer sides. Confirm the L298N channel, wiring, connector, fuse, and thermal/current ratings before pairing motors; an L298N may be unsuitable for the measured stall current. If all four encoders must be observed independently, revise the electronics and introduce a versioned protocol rather than silently combining pulses.

The A1 auxiliary contact reports state only. A mechanically linked, normally closed main contact **must independently interrupt motor energy**; never route motor current through A1 or Arduino ground traces. The NEO-6M GPS is expected on a Jetson USB/UART adapter, the 2D LiDAR on USB, and the IMX219 on the Jetson CSI connector. Use a bidirectional level shifter wherever a 5 V signal could reach the Jetson's 3.3 V pins. Join logic grounds, keep motor current out of logic-ground paths, add bulk capacitance at the L298N, and power motors separately from the Jetson regulator.

The included udev rule matches an example Arduino VID/PID and should be narrowed with the board serial number on a multi-robot system.

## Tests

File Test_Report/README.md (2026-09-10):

# Test evidence

Generated logs and reports are not treated as proof unless they identify the
commit, configuration, equipment and test level. Use these evidence levels:

1. static/unit test
2. protocol mock
3. physics simulation
4. current-limited bench test
5. raised-wheel hardware test
6. bounded floor test

Do not commit private maps, raw GPS tracks or camera data. The acceptance
procedure and report template are in [`docs/testing.md`](../docs/testing.md).

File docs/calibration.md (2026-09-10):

# Calibration

Calibration converts the assembled robot—not catalogue values—into software parameters. Work on a stand first, use low limits, save raw data, and record environmental conditions and firmware/software revisions.

## Calibration order

```mermaid
flowchart LR
    A[Pin and polarity] --> B[Encoder counts]
    B --> C[Loaded wheel radius]
    C --> D[Effective wheel separation]
    D --> E[Motor feedforward / PID]
    E --> F[IMU]
    F --> G[Sensor extrinsics]
    G --> H[LiDAR / camera / range]
    H --> I[Estimator covariance]
```

Changing a wheel, tire pressure/material, gearbox, encoder decode mode, motor driver, IMU mount, or sensor bracket invalidates downstream calibration.

## 1. Direction and sign matrix

Lift all four wheels and cap PWM to the commissioning limit.

| Test | Required observation |
|---|---|
| Positive left-side command | Both left wheels drive forward together; left-side encoder position increases |
| Positive right-side command | Both right wheels drive forward together; right-side encoder position increases |
| Positive `linear.x` | All four wheels drive forward; both measured side velocities are positive |
| Positive `angular.z` | Robot convention is counter-clockwise viewed from above; right-side pair drives forward relative to the left |
| E-stop asserted | Both side outputs and all four motors are de-energized; status reports asserted |
| Command source removed | Both outputs reach zero within the validated 300 ms firmware watchdog bound plus measured actuation delay |

Correct wiring/polarity or explicit per-side sign parameters. Do not scatter minus signs among firmware, URDF, bridge, and estimator until a plot looks right.

## 2. Encoder counts per output revolution

“Pulses per revolution” may refer to one channel's cycles at the motor shaft, edges after quadrature decoding, or counts after the gearbox. Determine what the firmware reports.

1. Mark wheel and chassis at one angular reference.
2. Zero the count with motor power disabled.
3. Rotate the output wheel slowly for `N` complete revolutions in the positive direction.
4. Record total signed counts, repeat in the negative direction, and perform at least three trials.
5. Compute:

```text
counts_per_output_revolution = abs(total_counts) / N
radians_per_count            = 2*pi / counts_per_output_revolution
```

Use enough revolutions to expose missed edges and gear backlash. Repeat at increasing safe speeds with a logic analyzer or external revolution reference. The repository value `600` is only a commissioning placeholder.

## 3. Loaded wheel radius

Measure effective rolling radius on the floor under normal mass, not just unloaded wheel diameter.

1. Mark a straight course substantially longer than one wheel circumference.
2. Place all four wheels at repeatable starting marks and record both side-encoder counts.
3. Move slowly in a straight line without wheel slip; record actual tape-measured distance and count change per wheel.
4. Repeat forward/backward and in both course directions.
5. Estimate each side:

```text
distance_per_count = measured_distance / encoder_count_change
effective_radius   = distance_per_count * counts_per_revolution / (2*pi)
```

Investigate left/right differences before hiding them in multipliers: wheel wear, mounting eccentricity, load distribution, missed counts, or floor slip may be the real issue.

## 4. Effective wheel separation

The kinematic separation is tuned from motion and may differ from a caliper measurement because of tire scrub.

1. Start with the measured distance between left and right effective contact paths.
2. Command slow in-place rotations on the intended floor surface.
3. Measure actual yaw with an independent reference over multiple complete rotations in both directions.
4. Adjust the separation/multiplier using the ratio between measured and odometric yaw.
5. Validate on arcs as well as pivots.

For ideal differential-drive increments:

```text
delta_s     = (delta_right + delta_left) / 2
delta_theta = (delta_right - delta_left) / wheel_separation
```

Report repeatability and floor type. Do not tune geometry to compensate for a reversed encoder, saturated motor, loose wheel, or timing bug.

## 5. Motor response and closed-loop tuning

Characterize each side separately with the chassis lifted, then under controlled load:

- deadband and minimum repeatable speed;
- steady wheel speed versus PWM in both directions;
- startup overshoot and stop behavior;
- left/right asymmetry;
- battery-voltage dependence;
- driver/motor temperature and current;
- encoder noise and control-loop jitter.

Start with feedforward, then add feedback gains gradually. Limit integral accumulation and reset it when stopped/E-stopped. Validate step, ramp, reversal, and disturbance response. Acceptance bounds for speed error, overshoot, settling, current, and temperature remain `TBD` until component and operational requirements are documented.

## 6. MPU6050

### Mount and axis check

Document the transform from the breakout's printed/verified axes to `imu_link` and from `imu_link` to `base_link`. With the robot stationary and level, the gravity vector magnitude should be plausible and rotate into the expected axis when the chassis is placed on known faces. Rotate about one chassis axis at a time and check gyroscope sign.

### Bias and noise

1. Warm the complete robot to a representative state with motors disabled.
2. Keep it motionless on a rigid surface.
3. Record a long stationary dataset at the configured 50 Hz target.
4. Estimate mean gyro bias, accelerometer offsets, standard deviation, drift, and temperature dependence.
5. Repeat with compute load and motor operation (wheels lifted) to identify vibration/EMI effects.

The MPU6050 has no magnetometer. Do not publish a trusted absolute yaw merely by integrating its gyro; yaw will drift. If firmware emits raw data only, set the ROS IMU orientation covariance convention accordingly.

## 7. LiDAR

- Confirm the exact model and manufacturer driver.
- Place flat targets at independently measured distances and bearings.
- Verify `angle_min`, `angle_max`, increment direction, zero-bearing direction, scan time, range clipping, invalid-return encoding, and timestamp age.
- Measure the rigid transform from `base_link` to `lidar_link`.
- Check for chassis/mast returns and decide whether physical relocation or a documented filter is appropriate.
- Run with motors and regulators active to expose power/EMI issues.

Never erase real obstacles with a broad software mask just to produce a clean map.

## 8. Camera

Calibrate the exact camera, lens, focus, resolution, and crop used at runtime. A calibration for another IMX219 module or video mode is invalid.

Typical ROS calibration tooling uses a known checkerboard or ChArUco target. Measure square size with an appropriate instrument, fill the image with diverse target positions/angles, reject blurred samples, and save:

- image width/height and pixel format;
- intrinsic matrix and distortion model/coefficients;
- reprojection-error evidence;
- camera name and calibration date;
- `camera_link -> camera_optical_frame` convention;
- file path/checksum tied to the robot serial number.

Validate by rectifying new images and inspecting straight lines across the full field.

## 9. Ultrasonic range

Against targets with varied material, size, angle, and distance, characterize:

- minimum reliable range and saturation behavior;
- maximum useful range in the operating environment;
- offset from sensor face to reported range;
- field of view/side lobes;
- no-return/timeout representation;
- repeatability and temperature sensitivity;
- crosstalk if more than one module is installed.

Set `sensor_msgs/Range` min/max/field-of-view from this evidence. Treat out-of-range and missing echoes as unknown, not automatically clear.

## 10. GNSS

Test outdoors with an unobstructed sky view:

- cold and warm time to valid fix;
- fix status and satellite/quality indicators exposed by the driver;
- stationary scatter over time;
- repeatability at surveyed or independently known points;
- update rate and serial dropouts;
- behavior near buildings, vehicles, trees, and active electronics.

GNSS position alone does not supply reliable stationary heading. If course over ground is used, determine the minimum speed and quality threshold experimentally and reject it below that condition. Never navigate in latitude/longitude degrees as though they are local metres; use a validated local tangent/UTM transform and datum policy.

## 11. Extrinsics and time

Measure each sensor origin and orientation in a documented chassis coordinate system. Use metres and radians in configuration. Photograph measurement references. Validate transforms in RViz with live data and known targets.

For each data stream, measure:

- observed rate and jitter;
- transport latency and timestamp age;
- clock domain and synchronization method;
- behavior after disconnect/reconnect;
- timestamp monotonicity across MCU resets.

Time errors can masquerade as spatial calibration errors while the robot is moving.

## 12. Covariance and estimator validation

Covariance expresses observed uncertainty. Derive initial values from stationary/no-motion data and repeated known trajectories, then validate innovations and residuals. Never use zero covariance to mean “unknown”; ROS messages define specific unknown conventions, and an estimator may interpret zero as impossible precision.

Run at least:

- straight, reverse, pivot, circle, and figure-eight paths;
- stationary drift tests before and after warm-up;
- wheel-slip and mild obstruction tests under supervision;
- LiDAR-degraded and GNSS-degraded datasets;
- rosbag replay with identical configuration.

Store the raw bag, ground-truth method, parameter file, plots, result summary, and commit ID. A tuned parameter without provenance is not a calibration artifact.

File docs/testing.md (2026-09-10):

# Test and acceptance plan

Testing is staged so failure occurs with the least available energy. Never skip directly to autonomous motion because software unit tests or simulation pass.

## Evidence rules

Every result records:

- test ID/revision and pass criterion;
- robot ID/hardware revision;
- repository commit, firmware build, ROS/OS/driver versions and parameter checksums;
- equipment IDs/calibration status and environmental conditions;
- initial safety state and authorized test limits;
- command, stimulus and raw observation;
- logs/bags/plots/photos/video/instrument captures;
- pass/fail, anomalies, reviewer and date.

`PASS WITH NOTES` is not a waiver for a failed safety requirement. File defects and repeat after correction.

## Automated software checks

### Protocol and tools

```bash
python3 -m unittest discover -s tools/tests -v
python3 tools/robot_doctor.py
```

Cover golden CRC vectors, every schema boundary, signed numeric bounds, overlength/noise recovery, sequence wrap, fragmented/coalesced reads, stale telemetry, `BOOT` reset and fuzzed invalid input.

### Firmware build

```bash
pio run -d firmware/wildebeest_base
```

Warnings that can affect integer range, signedness, ISR sharing, timing, truncation or buffer capacity are release blockers. A successful compile does not validate pins or control behavior.

### ROS 2

```bash
./scripts/build.sh ros2
cd ros2_ws
colcon test --event-handlers console_direct+
colcon test-result --verbose
```

### ROS 1

```bash
./scripts/build.sh ros1
cd ros1_ws
catkin_make run_tests
catkin_test_results
```

CI should run clean builds, lint/static checks, protocol cross-implementation vectors, URDF/Xacro validation and launch smoke tests on declared OS/ROS profiles. Hardware-in-the-loop remains separately reported.

## Acceptance stages

```mermaid
flowchart LR
    H0[H0 review] --> H1[H1 power]
    H1 --> H2[H2 I/O]
    H2 --> H3[H3 lifted motion]
    H3 --> H4[H4 manual floor]
    H4 --> H5[H5 localization]
    H5 --> H6[H6 simulation regression]
    H6 --> H7[H7 autonomy]
    H7 --> H8[H8 endurance]
```

If a change affects an earlier stage, repeat that stage and everything downstream it can invalidate.

### H0 — design and documentation review

Pass when:

- exact parts/datasheets and as-built wiring/mechanics are recorded;
- safety-critical TBDs have resolved values, rationale and owner;
- power budget, fuse/wire/connector/regulator/battery analyses are reviewed;
- hard E-stop main and auxiliary contact design is reviewed;
- calibrated/test limits and controlled environment are declared;
- recovery and emergency procedures are available at the test site.

### H1 — unpowered and rail validation

Motor power remains disconnected. Pass when:

- continuity/polarity/isolation and connector keying match the schematic;
- no unexpected short or power-state backfeed exists;
- each rail starts on a current-limited source and remains within its documented tolerance under load/transient;
- A1 reads `LOW` when the NC auxiliary loop is healthy and `HIGH` when pressed, unplugged, or wire-open;
- the main E-stop contact independently opens the motor branch;
- no unexpected heating/current occurs.

### H2 — firmware and sensor bench

Motor branch remains open. Pass when:

- firmware boots with watchdog set and outputs disabled;
- correct `BOOT` protocol version is observed;
- CRC/schema/range rejection and resynchronization pass;
- command loss is detected at the configured 300 ms bound;
- hand-turned encoder count/sign/repeatability and max edge-rate margin pass;
- IMU axes/rate, sonar timeout/range and calibrated battery ADC are plausible;
- MCU reset/reconnect cannot reuse stale host state;
- telemetry rate, jitter and errors meet recorded criteria under full sensor load.

### H3 — lifted-wheel motion

Use a stable stand, current-limited motor source, hard E-stop observer and initial low PWM/speed limits. Pass when:

- no motion occurs on boot, connect, launch, reset, clear-stop or zero command;
- each side's motor direction and encoder sign match the matrix;
- all four wheels track low step/ramp commands; each same-side pair agrees without unstable oscillation;
- software stop, hard stop, USB pull and process kill stop output as required;
- pressed/unplugged/broken auxiliary sense states inhibit motion;
- driver/regulator/motor/compute current, voltage and temperature stay inside approved bounds;
- diagnostics identify injected encoder/IMU/range/protocol faults.

### H4 — supervised low-speed floor motion

Use an exclusion zone and physical barriers. Pass when:

- straight/reverse/pivot/arc motion matches odometry sign and command convention;
- stopping distance is measured for authorized load/surface/battery states and within the approved criterion;
- wheel radius/separation calibration meets repeatability criteria;
- dead-man/command timeout, software stop and hard stop work on the floor;
- no tipping, wheel unloading, diagonal rocking, cable contact, fastener movement or thermal issue occurs;
- post-run mechanical and battery inspection passes.

### H5 — sensing and localization

Pass when:

- TF graph is connected with unique owners and measured extrinsics;
- each sensor rate, timestamp age, frame, covariance, range/quality and disconnect behavior meets its criterion;
- encoder/IMU local odometry is validated on known trajectories;
- LiDAR map scale/alignment and loop closure are credible;
- GNSS, if used, passes outdoor quality/multipath and heading-strategy tests;
- estimator innovations/drift are reviewed, not just visually pleasing;
- stale/degraded sensor injection causes the required safe behavior.

### H6 — simulation and replay regression

Pass all applicable scenarios in [simulation](software/simulation.md), including command loss, obstacle, stale scan, reset and localization anomaly. Compare ROS 1/ROS 2 interface behavior. List any physics/sensor simplifications.

### H7 — supervised autonomous mission

Begin with one short, low-speed goal in a controlled mapped area. Pass when:

- preflight and manual checkout pass immediately beforehand;
- planner/controller honor final footprint and motion limits;
- static and appearing obstacle cases meet declared clearance/stop requirements;
- localization stays inside the declared error envelope;
- observer can stop the robot throughout;
- no uncommanded recovery crosses barriers or exclusion boundaries;
- repeated trials meet the predefined success criterion without ignored faults.

### H8 — endurance, thermal and maintenance baseline

Define duration/duty cycle from the mission and component ratings (`TBD` until H0). Exercise worst approved compute, sensor, motor, payload, surface and ambient conditions. Pass when rails, current, temperatures, message age, CPU/memory/storage, CRC/watchdog/reset counts, localization and mechanical retention remain within declared limits. Inspect immediately after the run and again after cooldown.

## Core fault-injection matrix

| Fault | Safe expected result | Stage |
|---|---|---|
| No valid `CMD` for 300 ms | MCU motor output disabled; watchdog diagnostic | H2/H3/H4 |
| USB unplugged | Same stop; host reports disconnected/stale | H3/H4 |
| Base bridge killed | MCU stop; restart remains stopped until deliberate command | H3/H4 |
| Bad CRC/out-of-range command | Ignored, diagnosed, watchdog not refreshed | H2/H3 |
| Arduino reset mid-run | Outputs safe; host detects `BOOT`; no tick jump actuation | H3/H4 |
| Hard E-stop pressed | Main motor energy interrupted; status asserted | H1/H3/H4 |
| E-stop sense cable unplug/open | Status asserted and firmware inhibits motion | H1/H3 |
| Encoder stuck/reversed/intermittent | Autonomous motion blocked; diagnostic/fault visible | H3/H5 |
| LiDAR/IMU/GNSS stream stale | Dependent behavior stops/degrades explicitly | H5/H7 |
| Duplicate `/cmd_vel` or TF owner | Preflight/test fails; no autonomous release | H5/H6 |
| Compute rail transient | No reset within approved load; otherwise redesign | H1/H8 |
| Disk full/log overload | Control remains safe; logging fault reported/mission aborted | H6/H8 |

## Quantitative criteria worksheet

Set these before the relevant test. Values must come from safety/mission needs and measured hardware capability.

| Metric | Criterion | Measurement method | Result |
|---|---|---|---|
| Hard-stop electrical interruption time | `TBD` | scope across motor rail/enable | |
| Watchdog command-to-output disable | 300 ms timeout plus documented processing/output delay | logic analyzer/scope + serial log | |
| Maximum stopping distance | `TBD` by surface/load/speed | marked course + synchronized video | |
| Wheel speed steady-state error/overshoot | `TBD` | encoder/reference plot | |
| Straight/path/yaw odometry error | `TBD` by distance/course | independent ground truth | |
| Sensor rate/jitter/maximum age | `TBD` each | ROS statistics/timestamp analysis | |
| Localization error and recovery time | `TBD` | independent ground truth | |
| Obstacle clearance/reaction distance | `TBD` | instrumented scenarios | |
| Rail droop/ripple/transient | `TBD` from device specs | oscilloscope at load connector | |
| Component/ambient temperature | `TBD` | logged sensors/thermal instrument | |
| Endurance duration/duty cycle | `TBD` | mission log | |

## Test report template

```text
Test ID / revision:
Requirement(s):
Robot / hardware revision:
Commit / firmware build / configuration checksum:
OS / ROS / drivers:
Date, location, personnel:
Environment / surface / payload / battery state:
Test equipment:
Initial state and safety controls:
Procedure and injected fault:
Expected result and numeric criterion:
Observed result and measurement uncertainty:
Artifact links:
PASS / FAIL:
Anomalies / corrective action / retest ID:
Reviewer:
```

Release notes must state the highest physical stage actually passed. Never turn “not run” into “pass” because a subsystem was absent.

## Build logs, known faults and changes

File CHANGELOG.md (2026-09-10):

# Changelog

All notable changes are recorded here. The project follows semantic versioning
once the hardware interface reaches 1.0.

## [Unreleased]

### Added

- Complete ROS 2 Jazzy autonomy workspace and ROS 1 Noetic compatibility workspace.
- CRC-protected Arduino base firmware with command watchdog and E-stop monitoring.
- Differential-drive model, localization/navigation configuration and simulation.
- Offline-capable rosbridge operator dashboard.
- Hardware BOM/commissioning workbook, safety manual and test procedures.
- Reproducible container, dev-container, CI and repository-quality tooling.

### Safety

- Added independent physical motor-power E-stop architecture and low-voltage guidance.
- Reclassified KY-040 modules as unsuitable for dependable wheel odometry.

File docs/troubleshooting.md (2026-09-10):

# Troubleshooting

Troubleshoot from the lowest safe layer upward. If motion, heat, odor, current, battery condition, polarity, or E-stop behavior is unexpected, press the hard E-stop, open the service disconnect, and diagnose unpowered. Software output is never sufficient evidence that an energized mechanism is safe to approach.

## First response tree

```mermaid
flowchart TD
    A[Problem observed] --> B{Unexpected motion, heat, smoke, damage, or failed stop?}
    B -->|Yes| C[Hard E-stop, isolate energy, clear people, follow incident plan]
    B -->|No| D{Can it be reproduced with motor power removed?}
    D -->|Yes| E[Use logic-only bench / mock / simulation]
    D -->|No| F[Use stand, current limit, observer, minimum command]
    E --> G[Identify failing layer]
    F --> G
    G --> H[Power and wiring]
    G --> I[Firmware and serial]
    G --> J[ROS graph and TF]
    G --> K[Sensor / estimator / navigation]
    H --> L[Fix one cause, capture evidence, rerun affected acceptance stage]
    I --> L
    J --> L
    K --> L
```

Do not change multiple signs, gains, frames, drivers and power wiring at once. Preserve the failing log and configuration before the change.

## Minimum diagnostic bundle

Collect these without secrets or unrelated personal data:

```bash
git rev-parse HEAD
cat /etc/os-release
uname -a
test -r /etc/nv_tegra_release && cat /etc/nv_tegra_release
python3 tools/robot_doctor.py
ls -l /dev/serial/by-id/
```

Then add the relevant ROS output:

=== "ROS 2"

    ```bash
    printenv | grep -E 'ROS|RMW|AMENT|COLCON'
    ros2 doctor --report
    ros2 node list
    ros2 topic list -t
    ros2 topic echo /diagnostics --once
    ```

=== "ROS 1"

    ```bash
    printenv | grep -E 'ROS|CATKIN'
    roswtf
    rosnode list
    rostopic list -v
    rostopic echo -n 1 /diagnostics
    ```

If the directory is not a Git checkout, record the source archive name/checksum instead of a commit.

## Power and reset problems

| Symptom | Likely causes | Safe checks | Corrective direction |
|---|---|---|---|
| Nothing powers | Open fuse/disconnect, connector/polarity, regulator not enabled | Battery absent first: continuity; then current-limited rail measurement | Restore reviewed power path; never bypass protection |
| Jetson resets when motors start | Rail droop, shared high-current return, regulator transient/thermal limit, EMI | Wheels lifted; scope at Jetson connector, log current, test logic from separate bench source | Redesign distribution/regulation/grounding, suppress motor noise, validate margin |
| USB disconnects under PWM | Ground shift, cable/connector, EMI, host power management | Motor branch off versus on comparison; inspect kernel log; scope ground/rail | Reroute/shorten/secure cable, correct returns/shielding, address source—not retries alone |
| Fuse opens | Short, stall, undersized protection relative to normal load, failed driver | Isolate branches; resistance/controlled current tests; inspect motor/driver | Fix cause and re-run power analysis; never fit a larger fuse without design review |
| L298N/regulator hot | Excess current/voltage drop, poor airflow, overload, high switching duty | Stop; measure current/temperature within controlled plan | Reduce load only within requirements or replace/redesign with suitable device |
| Battery reading wrong | Unsafe/wrong divider, ADC reference/tolerance, missing common reference, saturation | Disconnect pack; inspect divider; inject known safe voltages; compare calibrated meter | Correct hardware and scaling; keep low-voltage stop disabled until validated |

Never probe a loose energized robot. Secure it, use insulated/appropriate probes, and plan where hands will be before applying energy.

## Arduino does not appear

1. Keep motor power disconnected.
2. Confirm the USB cable supports data and try a known-good port/cable.
3. Inspect `dmesg --follow` or the platform's device log during reconnect.
4. List `/dev/serial/by-id/` and compare USB attributes with the udev rule.
5. Check group membership and session refresh; do not solve access by running ROS as root.
6. Close PlatformIO monitor, Arduino IDE, ModemManager interaction, or another bridge that may hold the port.
7. Confirm baud 115200 and that only one process opens the device.

If the port repeatedly disappears under motor load, return to power/EMI diagnosis.

## Serial connects but diagnostics stay stale

| Observation | Interpretation/action |
|---|---|
| No `BOOT` after MCU reset | Wrong device/baud, firmware absent, TX path blocked; inspect raw serial with motors unpowered |
| `BOOT` seen but protocol version rejected | Firmware/bridge drift; rebuild matching commit, do not bypass version check |
| CRC error count rises | Noise, competing reader/writer, baud mismatch, implementation drift; compare golden vectors and raw bytes |
| `ERR ... RANGE` | Host command exceeds firmware ±450 mm/s or ±1800 mrad/s, or field invalid |
| `ERR ... SCHEMA` | Malformed software-stop frame |
| `ERR ... TYPE` | Incompatible message type/version |
| Sequence gaps | Dropped/corrupt data or expected interleaving; remember ODOM/IMU/RANGE share telemetry sequence |
| Watchdog always set | No valid in-range `CMD` within 300 ms; inspect command ownership, rate, CRC and E-stop state |
| Hard-stop always asserted | NC A1 auxiliary loop open/high, E-stop pressed, broken/unplugged wire, wrong contact/wiring |
| Hard-stop never asserts on wire break | Unsafe sense wiring/firmware mismatch; stop testing until fail-safe behavior is restored |

Use the reference codec/tests to distinguish framing from ROS:

```bash
python3 -m unittest discover -s tools/tests -v
python3 tools/mock_mcu.py --demo --seconds 2
```

## No motion

With wheels lifted and an observer at the hard stop, check in order:

1. Is motor power present at the driver input and absent/present as the hard E-stop changes?
2. Does A1 report healthy only when the NC auxiliary loop is intact?
3. Are watchdog, software-stop, hard-stop or optional low-voltage blocking flags set?
4. Is `/cmd_vel` owned by the intended multiplexer and updating faster than the watchdog?
5. Is the command inside both ROS and firmware limits?
6. Are L298N ENA/ENB jumpers and logic-supply mode correct for the actual board?
7. Do PWM/direction pins change at the Arduino and driver input?
8. Are motor outputs and motor winding continuous?
9. Is target ramp/PWM deadband/closed-loop tuning preventing initial motion?

Do not clear a hard stop or inflate gains to hide a wiring/configuration fault.

## Motion direction or odometry is wrong

Use the [calibration sign matrix](calibration.md#1-direction-and-sign-matrix). Test one wheel at a time.

| Symptom | Most probable issue |
|---|---|
| Wheel moves forward, ticks decrease | Encoder A/B phase or encoder inversion for that side |
| Ticks increase by hand forward, motor drives backward | Motor leads/direction inversion for that side |
| Robot drives backward for positive `linear.x` | Both motor conventions wrong or body command sign changed |
| Positive `angular.z` turns clockwise | Left/right mapping or angular convention wrong |
| RViz wheels/robot move opposite physical convention | URDF joint axis or ROS bridge sign; do not change calibrated firmware blindly |
| Odom arcs during straight travel | Radius mismatch, missed counts, drag/load asymmetry, slip, loose wheel |

Choose one canonical correction layer and document it. Re-run all direction, straight, pivot and watchdog tests.

## Speed oscillation, noise or poor low-speed control

- Verify counts/revolution definition and control-loop `dt` first.
- Plot target, measured wheel speed, PWM, battery voltage and flags.
- Check encoder edge quality and missed/noisy counts with motors off/on.
- Characterize deadband/feedforward before increasing integral gain.
- Look for saturation, integral wind-up, loose coupling, gearbox backlash and wheel lift.
- Ensure the L298N can supply the required loaded voltage/current without thermal limiting.
- Tune one controlled variable at a time and preserve before/after logs.

An Arduino Uno with low-resolution encoders may not support smooth very-low-speed control. That is a hardware/control-bandwidth limit, not necessarily a PID defect.

## IMU problems

| Symptom | Check |
|---|---|
| No IMU frames and error flag | MPU enabled, address, supply, SDA/SCL continuity, pull-up voltage, initialization |
| Axes/sign wrong | Breakout-to-`imu_link` transform and physical orientation |
| Acceleration/gyro spikes with motors | Mount vibration, motor EMI, ground/power noise, I²C integrity |
| Yaw drifts while still | Expected gyro integration drift; MPU6050 has no magnetometer; estimate bias and do not claim absolute heading |
| Filter diverges | Units, timestamps, frame, gravity removal, duplicated correlated inputs, covariance too small |

Do not publish an invented orientation to satisfy an estimator input.

## Ultrasonic problems

- A timeout means unknown/no echo, not maximum clear range.
- Check trigger with a logic analyzer and echo only within safe electrical levels.
- Test a large hard perpendicular target before soft/angled/narrow targets.
- Inspect mount obstruction and motor acoustic/electrical interference.
- With multiple sensors, trigger sequentially and identify crosstalk experimentally.
- Age out old ROS messages when the firmware omits a timed-out sample.

## LiDAR problems

| Symptom | Check |
|---|---|
| Device absent | Exact USB/serial identity, supply/current, cable, permission, vendor driver |
| Scan mirrored/reversed | Driver angle ordering and `lidar_link` orientation |
| Map scale wrong | LiDAR range units, wheel geometry/odometry scale, time synchronization |
| Chassis visible | Physical placement, measured transform, narrowly justified mask |
| Dropouts under load | Power/USB bandwidth/EMI/thermal and driver logs |
| RViz shows scan but navigation ignores it | Frame connectivity, timestamp age, QoS (ROS 2), costmap topic/source configuration |

## IMX219 camera problems

Power the Jetson off before touching the CSI ribbon. Verify contact orientation, connector latch, camera/carrier compatibility and NVIDIA Argus/V4L pipeline outside ROS first. A generic UVC driver is not automatically suitable for a CSI IMX219.

If ROS 2 runs on a workstation while the Nano owns CSI, validate the chosen image transport for resolution, encoding, latency, jitter, drops, clock alignment, CPU/GPU use and privacy. Lowering resolution may hide bandwidth symptoms but changes camera calibration.

## GNSS problems

- Test outside with clear sky; indoors is not a valid acquisition benchmark.
- Confirm UART voltage, crossed RX/TX, baud, antenna and NMEA stream before ROS.
- Preserve `NavSatStatus`; do not convert no-fix to `(0,0)`.
- Inspect covariance/quality and stationary scatter.
- Multipath near buildings/vehicles/trees can create plausible but wrong positions.
- Position fixes do not provide trustworthy stationary yaw; verify heading strategy.
- Verify local projection/datum and metres-versus-degrees handling before fusion.

## TF and visualization problems

=== "ROS 2"

    ```bash
    ros2 run tf2_tools view_frames
    ros2 run tf2_ros tf2_echo map base_link
    ros2 topic info /tf --verbose
    ros2 topic info /joint_states --verbose
    ```

=== "ROS 1"

    ```bash
    rosrun tf2_tools view_frames.py
    rosrun tf tf_echo map base_link
    rostopic info /tf
    rostopic info /joint_states
    ```

Diagnose the first missing/duplicated edge, not the final RViz error. Common causes are mixed simulated/wall time, future/old sensor stamps, duplicate `odom -> base_link`, missing static sensor transform, inconsistent leading namespace/frame prefix, and two joint-state publishers.

## Navigation does not move or is unsafe

Do not bypass safety gates to make the planner move. Check:

- localization and transform age;
- `/scan` content/frame/age and costmap source;
- footprint and inflation against measured robot envelope;
- map scale/origin and initial pose;
- command multiplexer priority/timeouts;
- firmware hard/software/watchdog flags;
- velocity/acceleration limits and controller progress tolerances;
- local/global plan and recovery behavior;
- unknown/free/clearing semantics around missing sensor data.

If navigation moves toward an obstacle, hard-stop first, then reproduce in simulation or bag replay with actuation isolated.

## Escalation information

A useful issue contains the smallest safe reproduction, expected/actual behavior, exact versions/configuration, diagnostics, relevant raw protocol or bag slice, and acceptance stage. Redact secrets, faces, precise private locations and unrelated network information. State explicitly whether motor power was connected and whether any safety function failed.

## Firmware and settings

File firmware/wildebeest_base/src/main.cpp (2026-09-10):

#include <Arduino.h>
#include <Wire.h>
#include <math.h>
#include <stdio.h>
#include <string.h>

#include "BatterySafety.h"
#include "Config.h"
#include "MotorController.h"
#include "Protocol.h"

namespace {

volatile int32_t leftTicks = 0;
volatile int32_t rightTicks = 0;

wb::LineReceiver receiver;
wb::WheelController leftMotor(wb::LEFT_PWM_PIN, wb::LEFT_IN1_PIN, wb::LEFT_IN2_PIN,
                              wb::LEFT_MOTOR_INVERTED);
wb::WheelController rightMotor(wb::RIGHT_PWM_PIN, wb::RIGHT_IN1_PIN, wb::RIGHT_IN2_PIN,
                               wb::RIGHT_MOTOR_INVERTED);

uint16_t telemetrySequence = 0;
uint16_t statusFlags = wb::FLAG_WATCHDOG;
unsigned long lastCommandMs = 0;
unsigned long lastControlMs = 0;
unsigned long lastOdomMs = 0;
unsigned long lastImuMs = 0;
unsigned long lastRangeMs = 0;
unsigned long lastBatteryMs = 0;
unsigned long protocolFaultUntilMs = 0;

float requestedLeftRadS = 0.0F;
float requestedRightRadS = 0.0F;
float rampedLeftRadS = 0.0F;
float rampedRightRadS = 0.0F;
float measuredLeftRadS = 0.0F;
float measuredRightRadS = 0.0F;
int32_t previousLeftTicks = 0;
int32_t previousRightTicks = 0;
uint16_t batteryMv = 0;
uint16_t frontRangeMm = 0;
bool softEstop = false;
bool imuAvailable = false;
// Fail closed until the first valid battery sample only when the optional
// cutoff is explicitly compiled in.
bool lowVoltageMotorStopActive = wb::ENABLE_LOW_VOLTAGE_MOTOR_STOP;

enum class RangePhase : uint8_t { IDLE, TRIGGER_HIGH, WAIT_RISE, WAIT_FALL };
RangePhase rangePhase = RangePhase::IDLE;
unsigned long rangePhaseStartedUs = 0;
unsigned long echoStartedUs = 0;

void leftEncoderIsr() {
  const bool direction = digitalRead(wb::LEFT_ENCODER_A_PIN) == digitalRead(wb::LEFT_ENCODER_B_PIN);
  leftTicks += (direction ^ wb::LEFT_ENCODER_INVERTED) ? 1 : -1;
}

void rightEncoderIsr() {
  const bool direction = digitalRead(wb::RIGHT_ENCODER_A_PIN) == digitalRead(wb::RIGHT_ENCODER_B_PIN);
  rightTicks += (direction ^ wb::RIGHT_ENCODER_INVERTED) ? 1 : -1;
}

void snapshotTicks(int32_t& left, int32_t& right) {
  noInterrupts();
  left = leftTicks;
  right = rightTicks;
  interrupts();
}

bool elapsed(unsigned long now, unsigned long then, unsigned long period) {
  return static_cast<unsigned long>(now - then) >= period;
}

void sendError(uint16_t sequence, const char* code) {
  char body[64];
  snprintf(body, sizeof(body), "ERR,%u,%s", sequence, code);
  wb::writeFrame(Serial, body);
}

void markProtocolFault() {
  statusFlags |= wb::FLAG_PROTOCOL_ERROR;
  protocolFaultUntilMs = millis() + 1000UL;
}

bool parseCommand(char* body) {
  char* save = nullptr;
  const char* type = strtok_r(body, ",", &save);
  const char* sequenceText = strtok_r(nullptr, ",", &save);
  long sequenceLong = 0;
  if (type == nullptr || !wb::parseLongStrict(sequenceText, 0, 65535, sequenceLong)) return false;
  const uint16_t sequence = static_cast<uint16_t>(sequenceLong);

  if (strcmp(type, "CMD") == 0) {
    const char* linearText = strtok_r(nullptr, ",", &save);
    const char* angularText = strtok_r(nullptr, ",", &save);
    long linear = 0;
    long angular = 0;
    if (!wb::parseLongStrict(linearText, -wb::MAX_LINEAR_MM_S, wb::MAX_LINEAR_MM_S, linear) ||
        !wb::parseLongStrict(angularText, -wb::MAX_ANGULAR_MRAD_S,
                            wb::MAX_ANGULAR_MRAD_S, angular) ||
        strtok_r(nullptr, ",", &save) != nullptr) {
      sendError(sequence, "RANGE");
      return false;
    }
    const float linearMps = static_cast<float>(linear) / 1000.0F;
    const float angularRadS = static_cast<float>(angular) / 1000.0F;
    requestedLeftRadS = (linearMps - angularRadS * wb::WHEEL_SEPARATION_M * 0.5F) /
                        wb::WHEEL_RADIUS_M;
    requestedRightRadS = (linearMps + angularRadS * wb::WHEEL_SEPARATION_M * 0.5F) /
                         wb::WHEEL_RADIUS_M;
    lastCommandMs = millis();
    statusFlags &= static_cast<uint16_t>(~wb::FLAG_WATCHDOG);
    return true;
  }

  if (strcmp(type, "PING") == 0 && strtok_r(nullptr, ",", &save) == nullptr) {
    char response[32];
    snprintf(response, sizeof(response), "PONG,%u", sequence);
    wb::writeFrame(Serial, response);
    return true;
  }

  if (strcmp(type, "ESTOP") == 0) {
    const char* stateText = strtok_r(nullptr, ",", &save);
    long state = 0;
    if (!wb::parseLongStrict(stateText, 0, 1, state) || strtok_r(nullptr, ",", &save) != nullptr) {
      sendError(sequence, "SCHEMA");
      return false;
    }
    // A hard-stop circuit always dominates and cannot be cleared in software.
    // Zero the target on either transition so release can never replay a
    // pre-stop command; motion requires a fresh CMD after ESTOP,0.
    softEstop = state == 1;
    requestedLeftRadS = 0.0F;
    requestedRightRadS = 0.0F;
    lastCommandMs = 0;
    statusFlags |= wb::FLAG_WATCHDOG;
    return true;
  }

  sendError(sequence, "TYPE");
  return false;
}

void serviceSerial() {
  while (Serial.available() > 0) {
    const char byte = static_cast<char>(Serial.read());
    const bool completedOverflow = byte == '\n' && receiver.overflowed();
    receiver.push(byte);
    if (completedOverflow) {
      markProtocolFault();
      continue;
    }
    if (!receiver.ready()) continue;
    char* body = wb::validateFrame(receiver.data());
    if (body == nullptr || !parseCommand(body)) markProtocolFault();
    receiver.consume();
  }
}

void updateSafety(unsigned long nowMs) {
  const bool hardEstop = digitalRead(wb::HARD_ESTOP_PIN) == wb::HARD_ESTOP_ACTIVE_STATE;
  const bool watchdog = lastCommandMs == 0 || elapsed(nowMs, lastCommandMs, wb::COMMAND_WATCHDOG_MS);
  if (hardEstop) {
    statusFlags |= wb::FLAG_HARD_ESTOP;
    // Latch the software stop too. Releasing the physical contact therefore
    // cannot restart a continuously publishing host; an operator must issue
    // ESTOP,0 and then a new velocity command.
    softEstop = true;
    requestedLeftRadS = 0.0F;
    requestedRightRadS = 0.0F;
    lastCommandMs = 0;
  } else {
    statusFlags &= static_cast<uint16_t>(~wb::FLAG_HARD_ESTOP);
  }
  if (softEstop) statusFlags |= wb::FLAG_SOFT_ESTOP;
  else statusFlags &= static_cast<uint16_t>(~wb::FLAG_SOFT_ESTOP);
  if (watchdog) statusFlags |= wb::FLAG_WATCHDOG;
  else statusFlags &= static_cast<uint16_t>(~wb::FLAG_WATCHDOG);
  if (static_cast<long>(nowMs - protocolFaultUntilMs) >= 0)
    statusFlags &= static_cast<uint16_t>(~wb::FLAG_PROTOCOL_ERROR);
  if (batteryMv > 0 && batteryMv <= wb::BATTERY_WARNING_MV) statusFlags |= wb::FLAG_LOW_BATTERY;
  else statusFlags &= static_cast<uint16_t>(~wb::FLAG_LOW_BATTERY);

  const bool previousLowVoltageStop = lowVoltageMotorStopActive;
  lowVoltageMotorStopActive = wb::ENABLE_LOW_VOLTAGE_MOTOR_STOP &&
      wb::nextLowVoltageMotorStop(lowVoltageMotorStopActive, batteryMv,
                                  wb::BATTERY_STOP_MV,
                                  wb::BATTERY_STOP_HYSTERESIS_MV);
  if (lowVoltageMotorStopActive != previousLowVoltageStop) {
    // Either edge invalidates freshness, so recovery cannot replay a target
    // accepted while voltage-based motion inhibition was active.
    requestedLeftRadS = 0.0F;
    requestedRightRadS = 0.0F;
    lastCommandMs = 0;
    statusFlags |= wb::FLAG_WATCHDOG;
  }
}

bool motionEnabled() {
  const uint16_t blocking = wb::FLAG_WATCHDOG | wb::FLAG_HARD_ESTOP | wb::FLAG_SOFT_ESTOP;
  return (statusFlags & blocking) == 0U && !lowVoltageMotorStopActive;
}

void updateControl(unsigned long nowMs) {
  if (!elapsed(nowMs, lastControlMs, wb::CONTROL_PERIOD_MS)) return;
  const unsigned long deltaMs = nowMs - lastControlMs;
  lastControlMs = nowMs;
  const float dt = static_cast<float>(deltaMs) / 1000.0F;
  int32_t currentLeft = 0;
  int32_t currentRight = 0;
  snapshotTicks(currentLeft, currentRight);
  const float radiansPerTick = 2.0F * PI / static_cast<float>(wb::ENCODER_TICKS_PER_REVOLUTION);
  measuredLeftRadS = static_cast<float>(currentLeft - previousLeftTicks) * radiansPerTick / dt;
  measuredRightRadS = static_cast<float>(currentRight - previousRightTicks) * radiansPerTick / dt;
  previousLeftTicks = currentLeft;
  previousRightTicks = currentRight;

  const bool enabled = motionEnabled();
  if (enabled) {
    rampedLeftRadS = wb::rampTarget(rampedLeftRadS, requestedLeftRadS);
    rampedRightRadS = wb::rampTarget(rampedRightRadS, requestedRightRadS);
  } else {
    rampedLeftRadS = 0.0F;
    rampedRightRadS = 0.0F;
  }
  leftMotor.setTarget(rampedLeftRadS);
  rightMotor.setTarget(rampedRightRadS);
  leftMotor.update(measuredLeftRadS, dt, enabled);
  rightMotor.update(measuredRightRadS, dt, enabled);
}

void sendOdometry(unsigned long nowMs) {
  if (!elapsed(nowMs, lastOdomMs, wb::ODOM_PERIOD_MS)) return;
  lastOdomMs = nowMs;
  int32_t left = 0;
  int32_t right = 0;
  snapshotTicks(left, right);
  char body[112];
  snprintf(body, sizeof(body), "ODOM,%u,%ld,%ld,%ld,%ld,%u,%u",
           static_cast<unsigned int>(telemetrySequence++),
           static_cast<long>(left), static_cast<long>(right),
           static_cast<long>(measuredLeftRadS * 1000.0F),
           static_cast<long>(measuredRightRadS * 1000.0F),
           static_cast<unsigned int>(batteryMv),
           static_cast<unsigned int>(statusFlags));
  wb::writeFrame(Serial, body);
}

bool initializeImu() {
  if (!wb::ENABLE_MPU6050) return false;
  Wire.beginTransmission(wb::MPU6050_ADDRESS);
  Wire.write(0x6B);  // PWR_MGMT_1
  Wire.write(0x00);  // wake; use internal 8 MHz clock until calibrated
  return Wire.endTransmission() == 0;
}

bool readImu(int16_t& axMg, int16_t& ayMg, int16_t& azMg, int32_t& gxMdps,
             int32_t& gyMdps, int32_t& gzMdps) {
  Wire.beginTransmission(wb::MPU6050_ADDRESS);
  Wire.write(0x3B);
  if (Wire.endTransmission(false) != 0) return false;
  if (Wire.requestFrom(wb::MPU6050_ADDRESS, static_cast<uint8_t>(14), static_cast<uint8_t>(true)) != 14)
    return false;
  auto read16 = []() -> int16_t {
    return static_cast<int16_t>((static_cast<uint16_t>(Wire.read()) << 8) | Wire.read());
  };
  const int16_t rawAx = read16();
  const int16_t rawAy = read16();
  const int16_t rawAz = read16();
  (void)read16();  // temperature
  const int16_t rawGx = read16();
  const int16_t rawGy = read16();
  const int16_t rawGz = read16();
  axMg = static_cast<int16_t>(static_cast<int32_t>(rawAx) * 1000L / 16384L);
  ayMg = static_cast<int16_t>(static_cast<int32_t>(rawAy) * 1000L / 16384L);
  azMg = static_cast<int16_t>(static_cast<int32_t>(rawAz) * 1000L / 16384L);
  gxMdps = static_cast<int32_t>(rawGx) * 1000L / 131L;
  gyMdps = static_cast<int32_t>(rawGy) * 1000L / 131L;
  gzMdps = static_cast<int32_t>(rawGz) * 1000L / 131L;
  return true;
}

void sendImu(unsigned long nowMs) {
  if (!elapsed(nowMs, lastImuMs, wb::IMU_PERIOD_MS)) return;
  lastImuMs = nowMs;
  if (!imuAvailable) return;
  int16_t ax = 0, ay = 0, az = 0;
  int32_t gx = 0, gy = 0, gz = 0;
  if (!readImu(ax, ay, az, gx, gy, gz)) {
    statusFlags |= wb::FLAG_IMU_ERROR;
    imuAvailable = false;
    return;
  }
  statusFlags &= static_cast<uint16_t>(~wb::FLAG_IMU_ERROR);
  char body[112];
  snprintf(body, sizeof(body), "IMU,%u,%d,%d,%d,%ld,%ld,%ld",
           static_cast<unsigned int>(telemetrySequence++), ax, ay, az,
           static_cast<long>(gx), static_cast<long>(gy), static_cast<long>(gz));
  wb::writeFrame(Serial, body);
}

void startRangeMeasurement(unsigned long nowUs) {
  digitalWrite(wb::ULTRASONIC_TRIGGER_PIN, HIGH);
  rangePhase = RangePhase::TRIGGER_HIGH;
  rangePhaseStartedUs = nowUs;
}

void serviceRange(unsigned long nowMs, unsigned long nowUs) {
  switch (rangePhase) {
    case RangePhase::IDLE:
      if (elapsed(nowMs, lastRangeMs, wb::RANGE_PERIOD_MS)) {
        lastRangeMs = nowMs;
        startRangeMeasurement(nowUs);
      }
      break;
    case RangePhase::TRIGGER_HIGH:
      if (static_cast<unsigned long>(nowUs - rangePhaseStartedUs) >= 10UL) {
        digitalWrite(wb::ULTRASONIC_TRIGGER_PIN, LOW);
        rangePhase = RangePhase::WAIT_RISE;
        rangePhaseStartedUs = nowUs;
      }
      break;
    case RangePhase::WAIT_RISE:
      if (digitalRead(wb::ULTRASONIC_ECHO_PIN) == HIGH) {
        echoStartedUs = nowUs;
        rangePhase = RangePhase::WAIT_FALL;
      } else if (static_cast<unsigned long>(nowUs - rangePhaseStartedUs) > 12000UL) {
        statusFlags |= wb::FLAG_RANGE_TIMEOUT;
        rangePhase = RangePhase::IDLE;
      }
      break;
    case RangePhase::WAIT_FALL:
      if (digitalRead(wb::ULTRASONIC_ECHO_PIN) == LOW) {
        const unsigned long echoUs = nowUs - echoStartedUs;
        frontRangeMm = static_cast<uint16_t>(constrain(echoUs * 10UL / 58UL, 20UL, 2000UL));
        statusFlags &= static_cast<uint16_t>(~wb::FLAG_RANGE_TIMEOUT);
        char body[48];
        snprintf(body, sizeof(body), "RANGE,%u,%u",
                 static_cast<unsigned int>(telemetrySequence++),
                 static_cast<unsigned int>(frontRangeMm));
        wb::writeFrame(Serial, body);
        rangePhase = RangePhase::IDLE;
      } else if (static_cast<unsigned long>(nowUs - echoStartedUs) > 12000UL) {
        statusFlags |= wb::FLAG_RANGE_TIMEOUT;
        rangePhase = RangePhase::IDLE;
      }
      break;
  }
}

void updateBattery(unsigned long nowMs) {
  if (!elapsed(nowMs, lastBatteryMs, wb::BATTERY_PERIOD_MS)) return;
  lastBatteryMs = nowMs;
  const uint16_t raw = analogRead(wb::BATTERY_SENSE_PIN);
  const float millivolts = static_cast<float>(raw) * wb::ADC_REFERENCE_V *
                           wb::BATTERY_DIVIDER_RATIO * 1000.0F / 1023.0F;
  const uint16_t sample = static_cast<uint16_t>(millivolts);
  batteryMv = batteryMv == 0 ? sample : static_cast<uint16_t>((batteryMv * 3UL + sample) / 4UL);
}

}  // namespace

void setup() {
  pinMode(wb::LEFT_ENCODER_A_PIN, INPUT_PULLUP);
  pinMode(wb::LEFT_ENCODER_B_PIN, INPUT_PULLUP);
  pinMode(wb::RIGHT_ENCODER_A_PIN, INPUT_PULLUP);
  pinMode(wb::RIGHT_ENCODER_B_PIN, INPUT_PULLUP);
  pinMode(wb::HARD_ESTOP_PIN, INPUT_PULLUP);
  pinMode(wb::ULTRASONIC_TRIGGER_PIN, OUTPUT);
  pinMode(wb::ULTRASONIC_ECHO_PIN, INPUT);
  digitalWrite(wb::ULTRASONIC_TRIGGER_PIN, LOW);

  leftMotor.begin();
  rightMotor.begin();
  attachInterrupt(digitalPinToInterrupt(wb::LEFT_ENCODER_A_PIN), leftEncoderIsr, CHANGE);
  attachInterrupt(digitalPinToInterrupt(wb::RIGHT_ENCODER_A_PIN), rightEncoderIsr, CHANGE);

  Serial.begin(wb::SERIAL_BAUD);
  Wire.begin();
  Wire.setClock(400000UL);
  imuAvailable = initializeImu();
  if (!imuAvailable) statusFlags |= wb::FLAG_IMU_ERROR;
  lastControlMs = millis();
  wb::writeFrame(Serial, "BOOT,0,WILDEBEEST_BASE,1");
}

void loop() {
  const unsigned long nowMs = millis();
  const unsigned long nowUs = micros();
  serviceSerial();
  updateBattery(nowMs);
  updateSafety(nowMs);
  updateControl(nowMs);
  serviceRange(nowMs, nowUs);
  sendImu(nowMs);
  sendOdometry(nowMs);
}

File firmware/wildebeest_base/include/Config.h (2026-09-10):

#pragma once

#include <Arduino.h>

namespace wb {

// Serial and scheduler -------------------------------------------------------
constexpr unsigned long SERIAL_BAUD = 115200UL;
constexpr uint16_t COMMAND_WATCHDOG_MS = 300;
constexpr uint16_t CONTROL_PERIOD_MS = 20;       // 50 Hz
constexpr uint16_t ODOM_PERIOD_MS = 50;          // 20 Hz
constexpr uint16_t IMU_PERIOD_MS = 20;           // 50 Hz
constexpr uint16_t RANGE_PERIOD_MS = 100;        // 10 Hz
constexpr uint16_t BATTERY_PERIOD_MS = 250;      // 4 Hz

// Four-wheel skid-steer geometry audited from the placed CAD meshes. The two
// motors on each side share a side command. Measure loaded radius and calibrate
// effective separation on the finished robot before autonomous use.
constexpr float WHEEL_RADIUS_M = 0.033622F;
constexpr float WHEEL_SEPARATION_M = 0.121843F;
constexpr int32_t ENCODER_TICKS_PER_REVOLUTION = 600;

// Command limits. A frame outside these limits is rejected, not clamped.
constexpr int16_t MAX_LINEAR_MM_S = 450;
constexpr int16_t MAX_ANGULAR_MRAD_S = 1800;
constexpr float MAX_WHEEL_RAD_S = 18.0F;

// L298N motor driver ---------------------------------------------------------
constexpr uint8_t LEFT_PWM_PIN = 5;
constexpr uint8_t LEFT_IN1_PIN = 7;
constexpr uint8_t LEFT_IN2_PIN = 8;
constexpr uint8_t RIGHT_PWM_PIN = 6;
constexpr uint8_t RIGHT_IN1_PIN = 9;
constexpr uint8_t RIGHT_IN2_PIN = 10;
constexpr bool LEFT_MOTOR_INVERTED = false;
constexpr bool RIGHT_MOTOR_INVERTED = true;
constexpr uint8_t PWM_DEADBAND = 35;
constexpr uint8_t PWM_MAX = 220;  // preserves control headroom and reduces stress

// Encoder inputs. CPR means the effective count produced by this exact ISR mode.
constexpr uint8_t LEFT_ENCODER_A_PIN = 2;
constexpr uint8_t LEFT_ENCODER_B_PIN = 4;
constexpr uint8_t RIGHT_ENCODER_A_PIN = 3;
constexpr uint8_t RIGHT_ENCODER_B_PIN = 12;
constexpr bool LEFT_ENCODER_INVERTED = false;
constexpr bool RIGHT_ENCODER_INVERTED = true;

// Safety and auxiliary IO ----------------------------------------------------
constexpr uint8_t ULTRASONIC_TRIGGER_PIN = 11;
constexpr uint8_t ULTRASONIC_ECHO_PIN = A0;
// Wire A1 through the normally-closed auxiliary contact to GND. Healthy = LOW;
// pressed, unplugged, or broken wire = HIGH via INPUT_PULLUP. The main E-stop
// contact must independently remove motor power; this input is only monitoring.
constexpr uint8_t HARD_ESTOP_PIN = A1;
constexpr uint8_t HARD_ESTOP_ACTIVE_STATE = HIGH;
constexpr uint8_t BATTERY_SENSE_PIN = A2;

// Divider defaults: 100 kOhm high side, 47 kOhm low side. Verify with a meter.
constexpr float ADC_REFERENCE_V = 5.0F;
constexpr float BATTERY_DIVIDER_RATIO = 3.1276596F;
constexpr uint16_t BATTERY_WARNING_MV = 6800;
constexpr uint16_t BATTERY_STOP_MV = 6600;
// When enabled, motion may re-arm at 6750 mV after stopping at 6600 mV.
// The gap avoids rapid enable/disable cycling around the stop threshold.
constexpr uint16_t BATTERY_STOP_HYSTERESIS_MV = 150;
constexpr bool ENABLE_LOW_VOLTAGE_MOTOR_STOP = false;
static_assert(BATTERY_STOP_MV + BATTERY_STOP_HYSTERESIS_MV <= BATTERY_WARNING_MV,
              "battery stop release must remain within the warning region");

// Controller values are safe starting points, not tuned values.
constexpr float PID_KP = 11.0F;
constexpr float PID_KI = 4.0F;
constexpr float PID_KD = 0.08F;
constexpr float FEEDFORWARD_PWM_PER_RAD_S = 10.0F;
constexpr float MAX_TARGET_STEP_RAD_S = 0.8F;  // per 20 ms control step

// MPU-6050 on the Uno I2C bus (A4 SDA / A5 SCL).
constexpr bool ENABLE_MPU6050 = true;
constexpr uint8_t MPU6050_ADDRESS = 0x68;

// Fault/status bits carried in ODOM telemetry.
enum StatusFlag : uint16_t {
  FLAG_WATCHDOG = 1U << 0,
  FLAG_HARD_ESTOP = 1U << 1,
  FLAG_SOFT_ESTOP = 1U << 2,
  FLAG_PROTOCOL_ERROR = 1U << 3,
  FLAG_IMU_ERROR = 1U << 4,
  FLAG_RANGE_TIMEOUT = 1U << 5,
  FLAG_LOW_BATTERY = 1U << 6,
};

}  // namespace wb

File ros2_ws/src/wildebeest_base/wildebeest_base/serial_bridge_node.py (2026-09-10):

"""ROS 2 node joining the Arduino protocol to standard mobile-robot topics."""

import math
import time
from typing import Optional

from diagnostic_msgs.msg import DiagnosticArray, DiagnosticStatus, KeyValue
from geometry_msgs.msg import TransformStamped, Twist
from nav_msgs.msg import Odometry
import rclpy
from rclpy.node import Node
from rclpy.qos import qos_profile_sensor_data
from sensor_msgs.msg import BatteryState, Imu, JointState, Range
from std_msgs.msg import Bool
from std_srvs.srv import Empty, SetBool
from tf2_ros import TransformBroadcaster

from .mock_controller import MockController
from .protocol import (
    encode_cmd,
    encode_estop,
    encode_ping,
    Frame,
    FrameStreamDecoder,
    ImuTelemetry,
    OdomTelemetry,
    parse_telemetry,
    ProtocolError,
    RangeTelemetry,
    validate_controller_boot,
)
from .transport import MockTransport, PySerialTransport, Transport, TransportError


class SerialBridge(Node):
    """Fail-closed bridge for the Wildebeest low-level controller."""

    def __init__(self) -> None:
        super().__init__('base_controller')
        self._declare_parameters()
        self._load_parameters()

        if self._transport_mode == 'serial':
            self._transport: Transport = PySerialTransport(self._port, self._baudrate)
        else:
            controller = MockController(
                wheel_radius_m=self._wheel_radius,
                wheel_separation_m=self._wheel_separation,
                ticks_per_revolution=self._ticks_per_revolution,
                command_timeout_s=self._command_timeout,
                max_wheel_rad_s=self._max_wheel_speed,
            )
            self._transport = MockTransport(controller)

        self._decoder = FrameStreamDecoder()
        self._tf_broadcaster = TransformBroadcaster(self) if self._publish_tf else None
        self._odom_pub = self.create_publisher(Odometry, '/wheel/odometry', 20)
        self._joint_pub = self.create_publisher(JointState, '/joint_states', 20)
        self._imu_pub = self.create_publisher(Imu, '/imu/data_raw', qos_profile_sensor_data)
        self._range_pub = self.create_publisher(
            Range, '/range/front', qos_profile_sensor_data
        )
        self._battery_pub = self.create_publisher(BatteryState, '/battery_state', 10)
        self._diagnostic_pub = self.create_publisher(DiagnosticArray, '/diagnostics', 10)
        self._cmd_sub = self.create_subscription(Twist, '/cmd_vel', self._on_cmd_vel, 10)
        self._estop_sub = self.create_subscription(
            Bool, '/wildebeest/estop', self._on_estop_topic, 10
        )
        self._estop_service = self.create_service(
            SetBool, '/base/set_estop', self._on_emergency_stop
        )
        self._reset_service = self.create_service(
            Empty, '/base/reset_odometry', self._on_reset_odometry
        )

        self._x = 0.0
        self._y = 0.0
        self._yaw = 0.0
        self._left_joint_position = 0.0
        self._right_joint_position = 0.0
        self._previous_left_ticks: Optional[int] = None
        self._previous_right_ticks: Optional[int] = None
        self._last_odom_s: Optional[float] = None
        self._last_imu_s: Optional[float] = None
        self._last_range_s: Optional[float] = None
        self._last_pong_s: Optional[float] = None
        self._last_command_s: Optional[float] = None
        self._last_ping_s = -math.inf
        self._last_connection_attempt_s = -math.inf
        self._command_timed_out = True
        self._firmware_flags = MockController.FLAG_WATCHDOG
        self._firmware_stopped = False
        self._host_estop_latched = True
        self._estopped = True
        self._controller_ready = False
        self._battery_v = math.nan
        self._sequence = 0
        self._last_telemetry_sequence: Optional[int] = None
        self._valid_frames = 0
        self._rejected_frames = 0
        self._sequence_gaps = 0
        self._transport_errors = 0
        self._unknown_frames = 0
        self._controller_errors = 0
        self._last_controller_error = ''
        self._firmware_identity = 'unknown'
        self._firmware_version = 'unknown'
        self._last_protocol_warning_s = -math.inf

        self._poll_timer = self.create_timer(1.0 / self._read_rate, self._poll)
        self._diagnostic_timer = self.create_timer(1.0, self._publish_diagnostics)
        self.get_logger().info(
            f'base bridge configured for {self._transport_mode} transport'
            + (f' on {self._port}' if self._transport_mode == 'serial' else '')
        )

    def _declare_parameters(self) -> None:
        defaults = {
            'transport': 'serial',
            'port': '/dev/wildebeest-base',
            'baudrate': 115200,
            'reconnect_interval_s': 2.0,
            'read_rate_hz': 100.0,
            'telemetry_timeout_s': 1.0,
            'command_timeout_s': 0.3,
            'ping_interval_s': 1.0,
            'max_linear_m_s': 0.45,
            'max_angular_rad_s': 1.8,
            'max_wheel_rad_s': 18.0,
            'wheel_radius_m': 0.033622,
            'wheel_separation_m': 0.121843,
            'ticks_per_revolution': 600,
            'publish_odom_tf': True,
            'odom_frame': 'odom',
            'base_frame': 'base_link',
            'imu_frame': 'imu_link',
            'range_frame': 'ultrasonic_front_link',
            'left_wheel_joints': [
                'left_front_wheel_joint',
                'left_rear_wheel_joint',
            ],
            'right_wheel_joints': [
                'right_front_wheel_joint',
                'right_rear_wheel_joint',
            ],
            'range_min_m': 0.02,
            'range_max_m': 2.0,
            'range_field_of_view_rad': 0.26,
            'estop_on_shutdown': True,
            'release_estop_on_connect': False,
        }
        for name, value in defaults.items():
            self.declare_parameter(name, value)

    def _load_parameters(self) -> None:
        def value(name):
            return self.get_parameter(name).value
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

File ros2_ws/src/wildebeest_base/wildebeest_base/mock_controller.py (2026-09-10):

"""Deterministic Arduino/controller model used by development and tests."""

from collections import deque
import math
from typing import Deque

from .protocol import encode_frame, Frame, ProtocolError


class MockController:
    """A small differential-drive plant implementing the serial contract.

    Time advances only through :meth:`advance`, which keeps unit tests fast and
    deterministic.  It models velocity slew, encoder counts, telemetry cadence,
    a command watchdog, and a latched emergency stop.
    """

    FLAG_WATCHDOG = 1 << 0
    FLAG_HARD_ESTOP = 1 << 1
    FLAG_SOFT_ESTOP = 1 << 2
    FLAG_PROTOCOL_ERROR = 1 << 3
    FLAG_IMU_ERROR = 1 << 4
    FLAG_RANGE_TIMEOUT = 1 << 5
    FLAG_LOW_BATTERY = 1 << 6

    def __init__(
        self,
        wheel_radius_m: float = 0.033622,
        wheel_separation_m: float = 0.121843,
        ticks_per_revolution: int = 600,
        telemetry_rate_hz: float = 30.0,
        command_timeout_s: float = 0.3,
        velocity_slew_rad_s2: float = 25.0,
        max_wheel_rad_s: float = 18.0,
    ) -> None:
        if wheel_radius_m <= 0.0 or wheel_separation_m <= 0.0:
            raise ValueError('wheel geometry must be positive')
        if ticks_per_revolution <= 0 or telemetry_rate_hz <= 0.0:
            raise ValueError('encoder resolution and telemetry rate must be positive')
        if command_timeout_s <= 0.0 or max_wheel_rad_s <= 0.0:
            raise ValueError('watchdog and wheel-speed limit must be positive')
        self.wheel_radius_m = wheel_radius_m
        self.wheel_separation_m = wheel_separation_m
        self.ticks_per_revolution = ticks_per_revolution
        self.telemetry_period_s = 1.0 / telemetry_rate_hz
        self.command_timeout_s = command_timeout_s
        self.velocity_slew_rad_s2 = velocity_slew_rad_s2
        self.max_wheel_rad_s = max_wheel_rad_s
        self.front_range_m = 1.5
        self.battery_v = 8.1

        self.elapsed_s = 0.0
        self._telemetry_accumulator_s = 0.0
        self._time_since_command_s = math.inf
        self._sequence = 0
        self._left_target = 0.0
        self._right_target = 0.0
        self._left_velocity = 0.0
        self._right_velocity = 0.0
        self._left_position = 0.0
        self._right_position = 0.0
        self.estopped = False
        self.watchdog_active = True
        self._queued: Deque[bytes] = deque()

    def handle_frame(self, frame: Frame) -> None:
        """Apply one checksum-verified host command."""
        if frame.kind == 'CMD':
            self._require_fields(frame, 2)
            linear_mm_s = self._integer(frame.fields[0], -450, 450, 'linear_mm_s')
            angular_mrad_s = self._integer(
                frame.fields[1], -1800, 1800, 'angular_mrad_s'
            )
            linear = linear_mm_s / 1000.0
            angular = angular_mrad_s / 1000.0
            left_target = (
                linear - angular * self.wheel_separation_m / 2.0
            ) / self.wheel_radius_m
            right_target = (
                linear + angular * self.wheel_separation_m / 2.0
            ) / self.wheel_radius_m
            peak = max(abs(left_target), abs(right_target))
            scale = min(1.0, self.max_wheel_rad_s / peak) if peak else 1.0
            if self.estopped:
                self._left_target = 0.0
                self._right_target = 0.0
            else:
                self._left_target = left_target * scale
                self._right_target = right_target * scale
            self._time_since_command_s = 0.0
            self.watchdog_active = False
        elif frame.kind == 'PING':
            self._require_fields(frame, 0)
            self._queued.append(encode_frame('PONG', frame.sequence))
        elif frame.kind == 'ESTOP':
            self._require_fields(frame, 1)
            engaged = self._integer(frame.fields[0], 0, 1, 'estop')
            self.estopped = bool(engaged)
            # Both edges invalidate the previous motion request. Releasing an
            # estop therefore requires a new CMD before motion can resume.
            self._left_target = 0.0
            self._right_target = 0.0
        else:
            raise ProtocolError(f'unsupported host command: {frame.kind}')

    def advance(self, duration_s: float) -> None:
        """Advance the model and enqueue any due telemetry."""
        if not math.isfinite(duration_s) or duration_s < 0.0:
            raise ValueError('duration_s must be finite and non-negative')
        if duration_s == 0.0:
            return
        remaining = duration_s
        maximum_step = min(0.01, self.telemetry_period_s)
        while remaining > 1e-12:
            step = min(maximum_step, remaining)
            remaining -= step
            self.elapsed_s += step
            self._telemetry_accumulator_s += step
            self._time_since_command_s += step
            if self._time_since_command_s > self.command_timeout_s:
                self.watchdog_active = True
                self._left_target = 0.0
                self._right_target = 0.0

            left_target = 0.0 if self.estopped else self._left_target
            right_target = 0.0 if self.estopped else self._right_target
            self._left_velocity = self._slew(self._left_velocity, left_target, step)
            self._right_velocity = self._slew(self._right_velocity, right_target, step)
            self._left_position += self._left_velocity * step
            self._right_position += self._right_velocity * step

            while self._telemetry_accumulator_s + 1e-12 >= self.telemetry_period_s:
                self._telemetry_accumulator_s -= self.telemetry_period_s
                self._emit_telemetry()

    def drain(self) -> bytes:
        """Return all queued controller output."""
        output = b''.join(self._queued)
        self._queued.clear()
        return output

    def boot(self) -> None:
        """Emit the same identity frame as a freshly reset controller."""
        self._left_target = 0.0
        self._right_target = 0.0
        self._time_since_command_s = math.inf
        self.watchdog_active = True
        self._queued.append(encode_frame('BOOT', 0, ('WILDEBEEST_BASE', 1)))

    @property
    def wheel_velocities(self):
        return self._left_velocity, self._right_velocity
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

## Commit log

2021-10-07 Mechanical_Design
    3D Mechanical Design for the Wildebeest_Pro
    [2.54 5PIN 90.SLDPRT, 220 35V CAPACITOR, LM2596 Buck Converter 4.0~40 to 1.3-37V Adjustable Step-Down Power Module with LED Display Volt meter.SLDPRT, A_GPS_ant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]
2026-09-10 feat: complete dual-ROS autonomous robot platform
    [2.54 5PIN 90.SLDPRT, 220 35V CAPACITOR, LM2596 Buck Converter 4.0~40 to 1.3-37V Adjustable Step-Down Power Module with LED Display Volt meter.SLDPRT, A_GPS_ant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]
2026-09-10 feat: add distinct sensor visual palette
    [materials.xacro, wildebeest.gazebo.xacro, wildebeest.urdf.xacro]

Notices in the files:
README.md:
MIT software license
